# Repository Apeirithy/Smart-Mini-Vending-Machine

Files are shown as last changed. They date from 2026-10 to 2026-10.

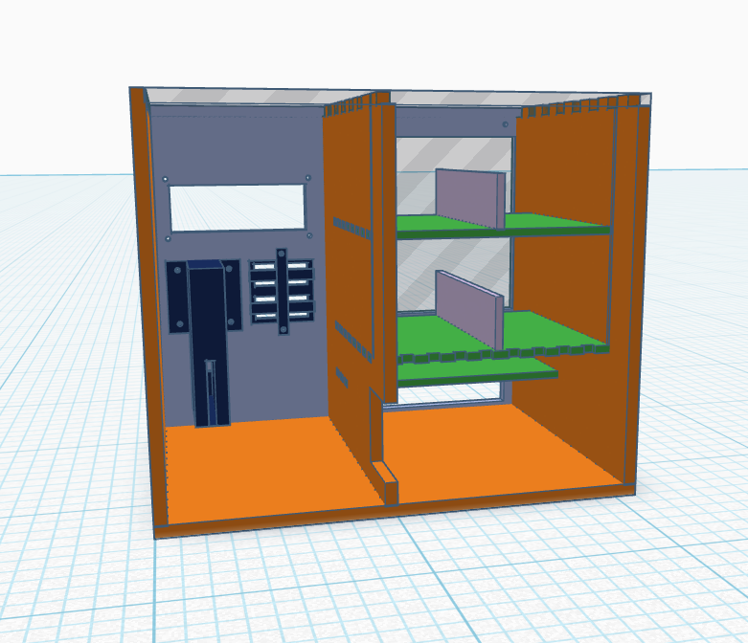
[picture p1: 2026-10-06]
3D_Mechanical_Design/Back View Prototype Design.png

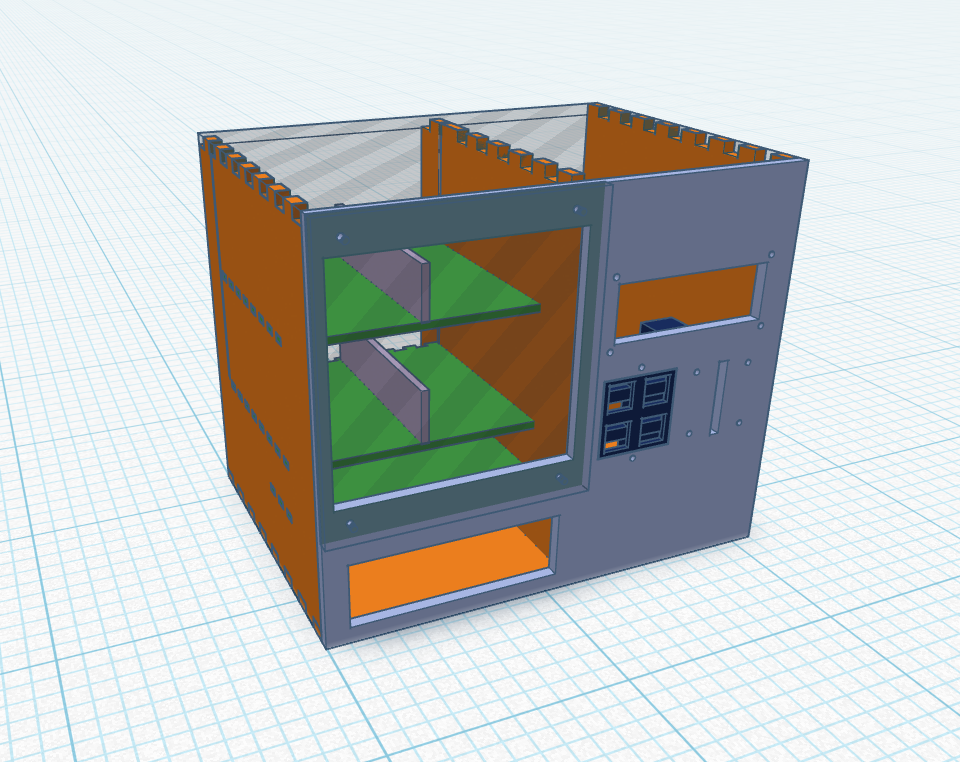
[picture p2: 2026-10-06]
3D_Mechanical_Design/Front View Prototype Design.png

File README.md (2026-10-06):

# Smart Mini Vending Machine for Electrical Components

A microcontroller-based embedded system designed to automatically distribute small electronic components. Built from scratch including custom PCB design, C-based bare-metal firmware (AVR-GCC), and 3D-modeled mechanical enclosures.

## Project Demonstration
* **Live Demo & Explanation:** https://youtu.be/EqsmP9JuczM

## System Architecture & Hardware
The system acts as a fully functional automated dispenser operated by coin insertion.
* **Microcontroller:** Arduino Nano (ATmega328P) acting as the main control unit.
* **Motor Control:** Dual DRV8833 Motor Drivers controlling 4 independent DC motors for product dispensing.
* **Sensors:** 
  * IR Optocoupler (Speed Sensor) for accurate coin insertion detection.
  * IR Obstacle Avoidance Sensors serving as drop detectors to verify successful product dispensation.
* **I/O Management:** Utilized PCF8574 I2C expansion board to manage push-button inputs, saving precious microcontroller pins.
* **Custom PCB:** The entire circuit was routed and engraved on a custom single-layer PCB using EasyEDA, replacing unreliable jumper wires.

> **View Hardware Schematic:** [Click here to view the EasyEDA Schematic](./Hardware_Schematics/Schematic_Vending_Machine.png)

## Mechanical & Enclosure Design
The physical chassis and dispensing mechanism were custom-designed to fit the specific needs of electrical components:
* **Enclosure:** Modeled in Tinkercad and fabricated using 5mm acrylic via laser cutting for a precise and professional finish.
* **Dispensing Mechanism:** Custom 3D-printed spiral pushers (coils) directly coupled to the DC motors.

> **View 3D Layout:** [Click here to view the Tinkercad Layout](./3D_Mechanical_Design/3D_Design_Part.stl)

## Firmware Logic (Finite State Machine)
The firmware is written in pure C (AVR-GCC) and relies on a robust Finite State Machine (FSM) to prevent conflicting operations.
1. **STATE_IDLE:** System awaits a hardware interrupt (PCINT) triggered by the optical coin sensor.
2. **STATE_SELECT:** Activates the I2C button matrix for user selection.
3. **STATE_RUNNING:** Actuates the DRV8833 motor driver until the drop sensor is triggered.
4. **STATE_FINISH:** Halts the motor, displays a "Thank You" message on the I2C 16x2 LCD, and resets the loop.

*A Watchdog Timer (WDT) is implemented to automatically recover the system in case of unexpected execution hangs.*

> **View Logic Flowchart:** [Click here to view the FSM Flowchart](./Firmware_Logic/Flowchart_Vending_Machine.png)

## Academic Report
For full technical specifications, hardware pin-mapping, and testing evaluations, please read the [Full Project Report (PDF)](./Reports/Vending_Machine_Report.pdf).

> **Visual Documentation:** Photos of the final built device, internal wiring, and documentation from the campus exhibition can be found on **pages 25–27** of the report.

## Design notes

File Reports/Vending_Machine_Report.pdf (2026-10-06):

i

## Laporan Tugas Akhir / Final Project

## CPEN6261010 - Microcontroller

## Smart Mini Vending Machine

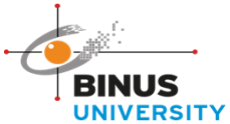
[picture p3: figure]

KELAS – LA40

Dibuat Oleh:

Nicholas Laurensius Halim | 2802428072

Computer Engineering

Faculty of Engineering - Computer Engineering

Binus University

Semester Ganjil 2025/2026

ii

Daftar Isi
Hal
Lembar Sampul
Daftar Isi

i
ii
Bab 1 – PENDAHULUAN | 3
Bab 2 – DESAIN SISTEM DAN METODOLOGI | 6
Bab 3 – IMPLEMENTASI | 12
Bab 4 – HASIL, PEMBAHASAN, KONTRIBUSI | 21
Bab 5 – KESIMPULAN DAN SARAN
Daftar Pustaka
Lampiran-Lampiran
Lampiran 1. Bukti Tambahan project / Link Video Penjelasan Lampiran 2. Datasheet
Lampiran 3. Source Code
Lampiran 4. Video Presentasi

23
24

25
28
29
30

BAB 1. PENDAHULUAN

### 1.1 Latar Belakang

Perkembangan teknologi otomasi dan sistem tertanam (embedded system) telah mendorong penerapan mikrokontroler dalam berbagai bidang, termasuk sistem penjualan otomatis (vending machine). Vending machine konvensional umumnya digunakan untuk menjual makanan atau minuman, namun memiliki keterbatasan dari segi ukuran, biaya, dan fleksibilitas sehingga kurang sesuai untuk kebutuhan penjualan barang berukuran kecil seperti komponen elektronik.

Dalam lingkungan pendidikan, laboratorium, dan pameran teknologi, kebutuhan akan sistem penyediaan komponen elektronik kecil seperti resistor, LED, atau modul sederhana secara cepat dan mandiri semakin meningkat. Sistem manual dinilai kurang efisien karena membutuhkan operator, rawan kesalahan, dan tidak mendukung otomasi. Oleh karena itu, dibutuhkan sebuah sistem vending machine berukuran mini yang sederhana, ekonomis, dan mudah dioperasikan.

Proyek Smart Mini Vending Machine for Electrical Components dirancang
sebagai | solusi | untuk | permasalahan | tersebut | dengan | memanfaatkan
mikrokontroler sebagai pengendali utama, sensor koin sebagai input pembayaran, push button sebagai media pemilihan produk, serta motor DC sebagai aktuator mekanis. Sistem ini menampilkan informasi kepada pengguna melalui LCD berbasis I2C dan bekerja secara otomatis berdasarkan alur logika yang tertanam dalam firmware.

Luaran dari tugas rancang ini berupa sebuah prototipe hardware lengkap dengan firmware yang mampu mendemonstrasikan prinsip kerja vending machine mini secara fungsional, dengan potensi penerapan jangka pendek sebagai media edukasi dan jangka panjang sebagai dasar pengembangan sistem vending machine skala kecil.

### 1.2 Rumusan Masalah

1. Bagaimana merancang sebuah vending machine mini yang mampu mendistribusikan komponen elektronik secara otomatis?
2. Bagaimana | mengimplementasikan | sistem | kontrol | berbasis
mikrokontroler untuk mengelola input koin, pemilihan produk, dan aktuasi motor?

3. Bagaimana merancang sistem yang sederhana, stabil, dan mudah digunakan tanpa menggunakan antarmuka yang kompleks seperti keypad?

### 1.3 Tujuan dan Manfaat

Tujuan dari proyek ini adalah:
1. Merancang dan merealisasikan prototipe vending machine mini berbasis mikrokontroler.
2. Mengimplementasikan sistem kontrol otomatis menggunakan sensor IR, push button, motor DC, dan LCD.
3. Mengembangkan firmware yang stabil dengan mekanisme state machine untuk mengatur alur kerja sistem.
Manfaat dari proyek ini meliputi :
1. Menjadi media pembelajaran praktis dalam memahami sistem embedded dan otomasi.
2. Memberikan solusi sederhana untuk distribusi komponen elektronik kecil secara mandiri.
3. Menjadi dasar pengembangan lebih lanjut menuju sistem vending machine yang lebih kompleks.

### 1.4 Ruang Lingkup

Ruang lingkup perancangan pada proyek ini dibatasi sebagai berikut:
1. Sistem hanya melayani satu transaksi untuk satu kali koin.
2. Pemilihan produk dilakukan menggunakan push button, bukan keypad.
3. Produk yang didistribusikan berupa komponen elektronik kecil.
4. Sistem menggunakan mikrokontroler berbasis Arduino Nano (ATmega328P).

### 5. Perancangan difokuskan pada pembuatan prototipe, bukan produk

komersial.

### 1.1 Tinjauan Pustaka

Vending machine merupakan sistem otomatis yang dirancang untuk mendistribusikan barang kepada pengguna setelah menerima input tertentu, seperti koin atau kartu. Sistem ini umumnya terdiri dari unit input, unit kontrol, dan aktuator mekanis. Pada skala komersial, vending machine memiliki sistem yang kompleks dan berukuran besar sehingga kurang sesuai untuk kebutuhan penjualan barang kecil dalam jumlah terbatas.

Mikrokontroler ATmega328P banyak digunakan dalam sistem embedded karena memiliki konsumsi daya rendah, jumlah pin yang mencukupi, serta dukungan ekosistem pengembangan yang luas. Penelitian dan proyek sebelumnya menunjukkan bahwa mikrokontroler ini efektif digunakan untuk sistem kontrol sederhana hingga menengah, termasuk pengendalian motor DC dan pengolahan input digital.

Sensor koin berbasis pulsa atau logika digital telah banyak diterapkan pada sistem vending machine sederhana. Sensor ini bekerja dengan mendeteksi perubahan logika tegangan saat koin melewati sensor, sehingga dapat digunakan sebagai pemicu transaksi. Selain itu, penggunaan push button sebagai media pemilihan produk dinilai lebih sederhana dan andal dibandingkan keypad, terutama untuk sistem dengan jumlah pilihan terbatas.

Beberapa penelitian dan prototipe vending machine berbasis mikrokontroler telah dikembangkan sebelumnya, namun umumnya ditujukan untuk produk konsumsi dan menggunakan antarmuka yang lebih kompleks. Keunikan dari perancangan ini terletak pada fokus pada distribusi komponen elektronik berukuran kecil, desain sistem yang ringkas, serta penggunaan antarmuka sederhana berbasis tombol yang sesuai untuk lingkungan edukasi dan pameran.

Hasil perancangan yang ditawarkan bersifat konstruktif karena menghasilkan sebuah sistem prototipe vending machine mini yang berfungsi secara nyata, memiliki daya guna sebagai alat pembelajaran, dan dapat dikembangkan lebih lanjut sesuai kebutuhan.

BAB 2. DESAIN SISTEM DAN METODOLOGI

### 2.1 Desain Sistem Secara Umum

Smart Mini Vending Machine for Electrical Components dirancang sebagai sebuah sistem tertanam (embedded system) yang mampu melakukan proses penjualan komponen elektronik secara otomatis. Sistem bekerja dengan mendeteksi koin sebagai input awal, menerima pilihan produk melalui tombol tekan (push button), menggerakkan motor DC untuk mendistribusikan barang, serta menampilkan informasi kepada pengguna melalui LCD berbasis I2C.

Sistem ini dikendalikan oleh sebuah mikrokontroler Arduino Nano yang berfungsi sebagai pusat pengolah data dan pengendali seluruh perangkat input dan output. Seluruh proses dikendalikan menggunakan pendekatan state machine untuk memastikan alur kerja sistem berjalan secara terstruktur dan stabil.

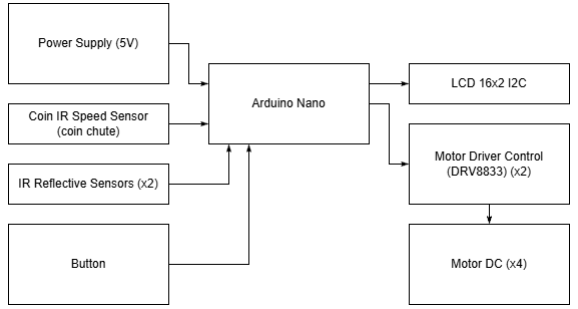
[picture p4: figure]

Blok Diagram Vending Machine

### 2.2 Desain Perangkat Keras

### 2.2.1 Arsitektur Perangkat Keras

Perangkat keras sistem Smart Mini Vending Machine terdiri dari beberapa modul utama, yaitu:

a) Mikrokontroler Arduino Nano digunakan sebagai pusat kendali sistem yang memproses sinyal dari sensor dan tombol, serta mengontrol motor DC dan LCD.

b) Sensor Optocoupler berfungsi untuk mendeteksi masuknya koin sebagai syarat awal untuk mengaktifkan sistem pemilihan produk.
c) Push Button (Melalui PCF8574) digunakan sebagai input pemilihan produk oleh pengguna. Modul PCF8574 digunakan untuk memperluas jumlah input menggunakan komunikasi I2C.
d) Motor DC dan Motor Driver digunakan sebagai aktuator untuk menggerakkan mekanisme pengeluaran produk. Motor driver berfungsi sebagai penguat arus agar motor dapat dikendalikan oleh mikrokontroler.
e) Sensor IR Obstacle Avoidance Module digunakan untuk mendeteksi bahwa produk telah berhasil dikeluarkan dari mesin.
f) LCD I2C digunakan sebagai antarmuka pengguna untuk menampilkan instruksi dan status sistem, seperti “Insert Coin”, “Select Product”, dan “Thank You”.
g) Power Supply, Sistem menggunakan suplai daya yang bersumber dari Adaptor 5V

### 2.2.2 Skema Rangkaian

Skema rangkaian menggambarkan hubungan antar komponen perangkat keras secara detail, termasuk koneksi pin antara Arduino Nano dengan sensor, modul I2C, motor driver, dan motor DC. Skema ini digunakan sebagai acuan dalam proses perakitan sistem dan memastikan seluruh komponen terhubung dengan benar.

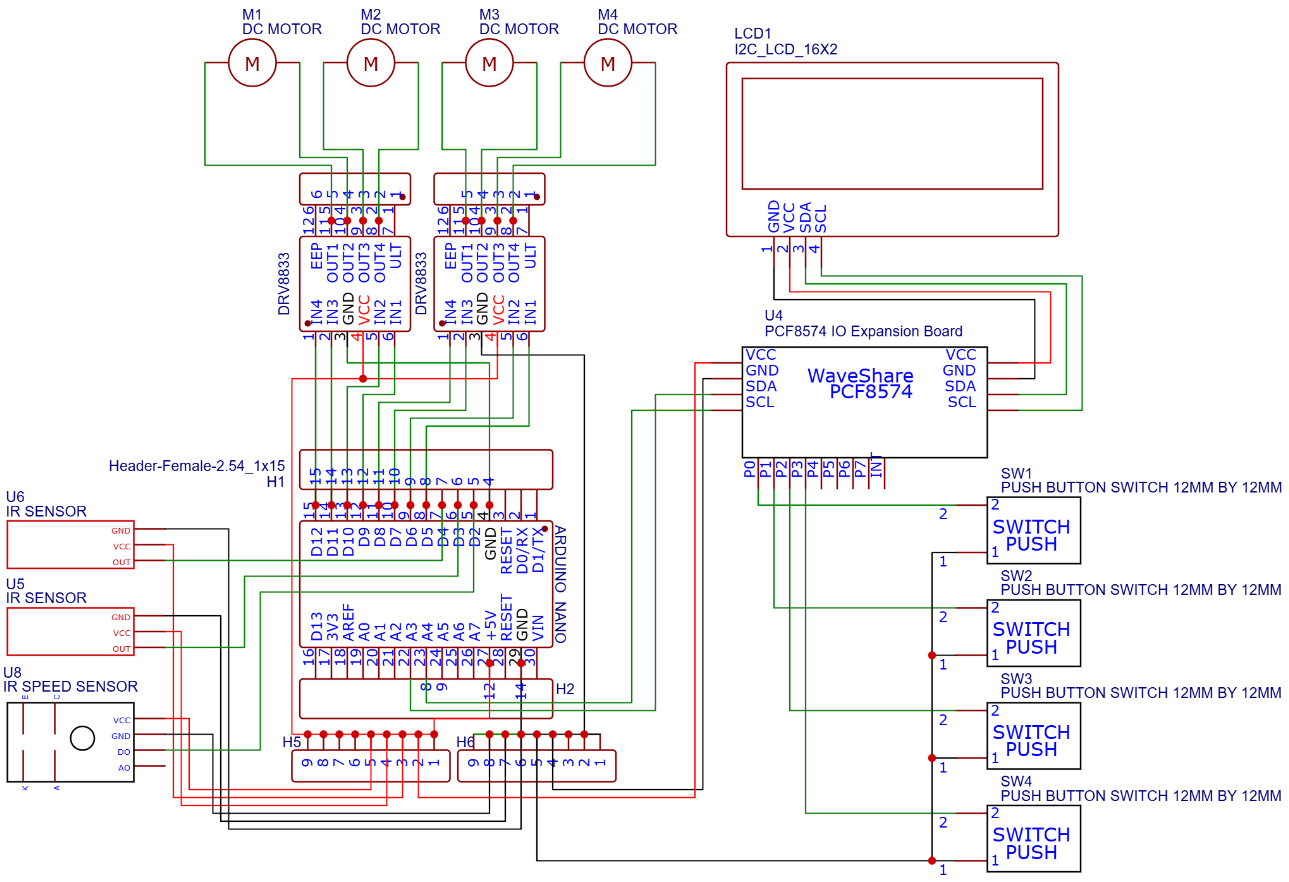
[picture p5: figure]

Skema Rangkaian Vending Machine

### 2.3 Desain Perangkat Lunak

Perangkat lunak pada sistem Smart Mini Vending Machine dikembangkan menggunakan bahasa pemrograman C berbasis AVR. Program dirancang menggunakan pendekatan finite state machine (FSM) untuk memastikan sistem dapat berpindah antar kondisi secara terkontrol dan terhindar dari perilaku tak terduga.

### 2.3.1 Konsep State Machine

Sistem memiliki beberapa kondisi utama, yaitu:

- IDLE: Sistem menunggu koin dimasukkan oleh pengguna dan menampilkan pesan awal.
- SELECT: Sistem menerima input pemilihan produk melalui push button.
- RUNNING: Sistem mengaktifkan motor DC untuk mengeluarkan produk.
- FINISH: Sistem menghentikan motor, menampilkan pesan terima kasih, dan kembali ke kondisi awal.

Pendekatan ini dipilih untuk meningkatkan stabilitas sistem dan memudahkan proses debugging serta pengembangan lanjutan.

### 2.3.2 Flowchart Sistem

Flowchart digunakan untuk menggambarkan alur logika kerja sistem secara visual, mulai dari inisialisasi hingga sistem kembali ke kondisi awal setelah transaksi selesai.

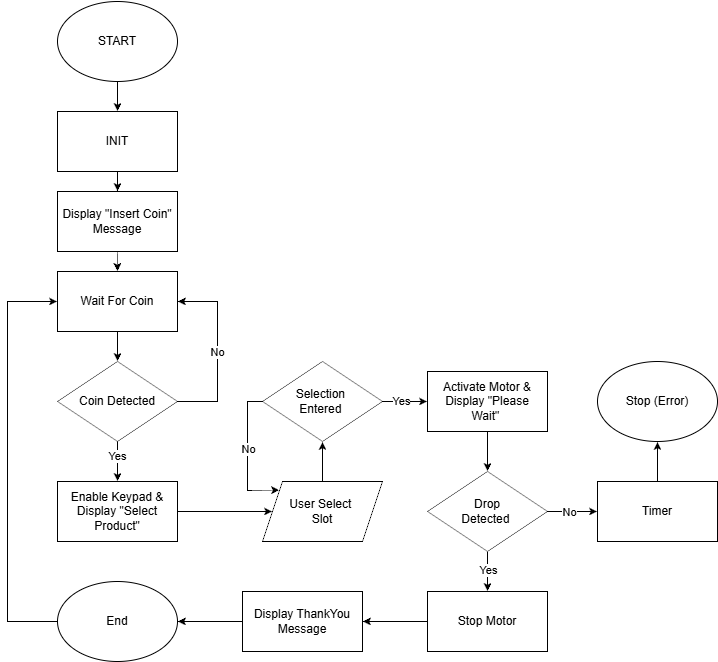
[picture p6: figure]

### 2.3.3 Pseudocode Sistem

Initialize system

Set system state to IDLE

Display "Insert Coin"

Loop forever:

If state is IDLE:

If coin detected:

Change state to SELECT

Display "Select Product"

If state is SELECT:

If button pressed:

Start selected motor

Change state to RUNNING

If timeout occurs:

Return to IDLE

If state is RUNNING:

If drop sensor triggered:

Stop motor

Change state to FINISH

If state is FINISH:

Display "Thank You"

Delay for a short time

Return to IDLE

### 2.4 Metodologi Kerja Sistem

Metodologi kerja sistem dimulai dengan inisialisasi seluruh perangkat keras dan perangkat lunak. Sistem kemudian berada pada kondisi siaga (IDLE) sambil menunggu masukan koin dari pengguna. Setelah koin terdeteksi, sistem berpindah ke mode pemilihan produk.

Pengguna memilih produk menggunakan tombol tekan, yang kemudian diproses oleh mikrokontroler untuk menentukan motor yang akan diaktifkan. Motor DC akan berputar hingga sensor drop mendeteksi bahwa produk telah berhasil dikeluarkan. Setelah proses selesai, sistem menampilkan pesan terima kasih dan kembali ke kondisi awal untuk siap menerima transaksi berikutnya.

### 2.5 Justifikasi Pemilihan Komponen

1. Arduino Nano

Dipilih karena ukurannya yang kecil, jumlah pin yang mencukupi, konsumsi daya rendah, serta kemudahan pemrograman dan debugging.

2. Push Button + PCF8574

Digunakan sebagai alternatif keypad untuk menyederhanakan antarmuka pengguna dan menghemat penggunaan pin mikrokontroler melalui komunikasi I2C.

3. LCD 16x2 I2C

LCD berbasis I2C digunakan sebagai media tampilan informasi kepada pengguna. Penggunaan antarmuka I2C memungkinkan pengurangan jumlah kabel dan pin yang digunakan dibandingkan LCD paralel konvensional. LCD ini dipilih karena memiliki ukuran yang kecil dan harga yang cukup murah.

4. Motor DC RS-310

Motor DC digunakan sebagai aktuator utama untuk menggerakkan mekanisme pengeluaran produk karena bisa bekerja hanya dengan 5V dan memiliki harga yang terjangkau. Motor DC RS-310 juga mampu menghasilkan torsi yang cukup untuk mendorong komponen elektronik berukuran kecil keluar dari mesin.

5. Driver 8833

Motor driver DRV8833 dipilih karena memiliki dua kanal (dual H-bridge) yang mampu mengendalikan dua motor DC secara independen dalam satu modul. Hal ini memungkinkan penghematan ruang dan komponen pada sistem. Selain itu, DRV8833 mampu bekerja pada tegangan rendah dan memiliki kemampuan proteksi arus berlebih (overcurrent protection).

6. IR Obstacle Avoidance Sensor Module

Digunakan untuk memastikan produk benar-benar keluar sebelum sistem menyelesaikan satu siklus transaksi. Dipilih karena harga yang murah dan simpel

7. IR Speed Sensor/ Optocoupler

Sensor koin yang digunakan pada sistem ini berbasis infrared optocoupler (IR speed sensor). Sensor ini dipilih karena memiliki desain berbentuk slot huruf U, yang memudahkan koin untuk melewati jalur sensor tanpa hambatan mekanis yang kompleks.

BAB 3. IMPLEMENTASI

### 3.1 Penjelasan Singkat Sistem yang telah dibuat

Sistem yang telah dibuat merupakan Smart Mini Vending Machine for Electrical Components, yaitu sebuah mesin vending berskala kecil yang dirancang untuk mendistribusikan komponen elektronik secara otomatis. Sistem ini menggunakan koin khusus sebagai metode pembayaran, tombol sebagai media pemilihan produk, serta motor DC sebagai aktuator untuk mengeluarkan barang.

Mikrokontroler Arduino Nano berfungsi sebagai pusat pengendali sistem yang menerima masukan dari sensor koin dan sensor pendeteksi barang, memproses input pengguna, serta mengendalikan motor DC melalui driver motor. Informasi kepada pengguna ditampilkan melalui LCD 16x2 berbasis komunikasi I2C.

### 3.2 Cara Kerja Sistem

Cara kerja sistem Smart Mini Vending Machine diawali dengan kondisi awal sistem dalam keadaan siaga (idle) dan menampilkan pesan “Insert Your Coin” pada LCD. Ketika koin khusus dimasukkan ke dalam slot, sensor IR speed sensor (optocoupler) mendeteksi keberadaan koin dan mengirimkan sinyal ke mikrokontroler.

Setelah koin terdeteksi, sistem berpindah ke mode pemilihan produk. LCD menampilkan pesan “Select Product”, dan pengguna dapat memilih produk menggunakan tombol yang tersedia. Tombol-tombol tersebut terhubung melalui modul I/O expander PCF8574.

Ketika salah satu tombol ditekan, mikrokontroler mengaktifkan motor DC yang sesuai dengan produk yang dipilih. Motor akan berputar untuk mendorong barang keluar dari slot. Sensor IR digunakan untuk mendeteksi jatuhnya barang sebagai indikator bahwa produk telah berhasil dikeluarkan.

Setelah barang terdeteksi, motor akan dihentikan, LCD menampilkan pesan “Thank You”, dan sistem kembali ke kondisi awal untuk melayani pengguna berikutnya.

### 3.3 Perancangan Perangkat Keras (Skematik, Perancangan hardware)

### 3.3.1 Desain Casing

Casing vending machine dirancang menggunakan akrilik dengan ketebalan 5 mm. Pemilihan material akrilik didasarkan pada kemudahan mendesain, biaya yang lebih murah dibanding 3D printing semua bagian, dan tampilan yang rapi dan profesional, serta kemudahan proses manufaktur menggunakan mesin laser cutting.

Desain casing dibuat menggunakan website Tinkercad, kemudian dipotong menggunakan mesin Epilog Laser Cutting untuk memastikan kerapihan hasil akhir.

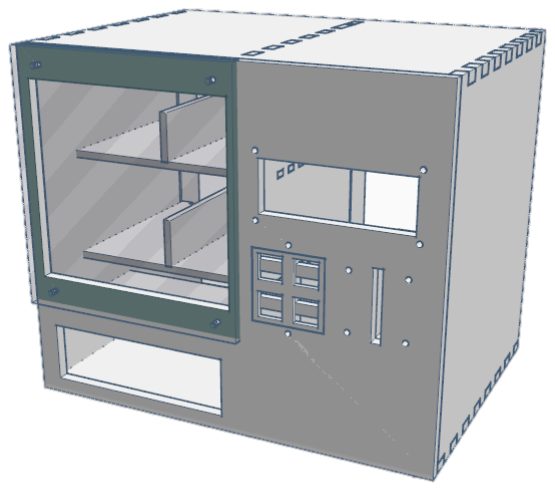
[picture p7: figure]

3D Desain Casing Vending Machine di Tinkercad

### 3.3.2 Mekanisme Mekanik

Beberapa komponen mekanik tambahan digunakan untuk mendukung fungsi sistem, antara lain:

- Slot koin, yang dirancang khusus agar sesuai dengan koin custom.
- Koin custom dengan ketebalan 0,3 mm, yang dirancang agar dapat melewati sensor secara konsisten. Ketebalan ini dipilih karena koin yang terlalu tebal berpotensi tersangkut, sedangkan koin yang terlalu tipis dapat menyebabkan pembacaan sensor tidak stabil.
- Mekanisme | pendorong | barang, | yang | dihubungkan
langsung dengan motor DC untuk mendorong komponen keluar dari slot.
- Casing penahan tombol, agar tombol dapat dipasang dengan rapi dan kokoh pada casing utama.
- Seluruh komponen mekanik tersebut dibuat menggunakan 3D printer, sehingga memungkinkan desain yang presisi dan mudah dimodifikasi.

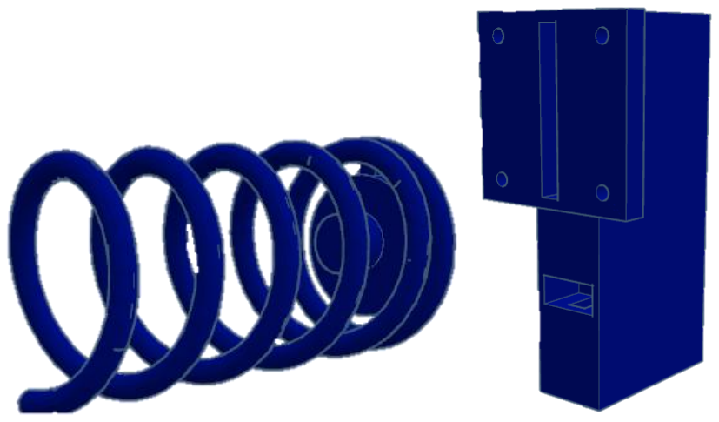
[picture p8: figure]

3D Desain Mekanisme Pendorong & Slot Koin

### 3.3.3 Perancangan PCB dan Rangkaian Elektronik

Rangkaian | elektronik | sistem | dirancang | menggunakan
EasyEDA, yang mencakup mikrokontroler Arduino Nano, driver motor DRV8833, modul I2C LCD, modul PCF8574, sensor IR, dan konektor pendukung lainnya.

PCB dibuat secara mandiri menggunakan metode engraving PCB, sehingga menghasilkan papan rangkaian yang lebih rapi, kuat, dan mengurangi kesalahan koneksi dibandingkan penggunaan kabel jumper.

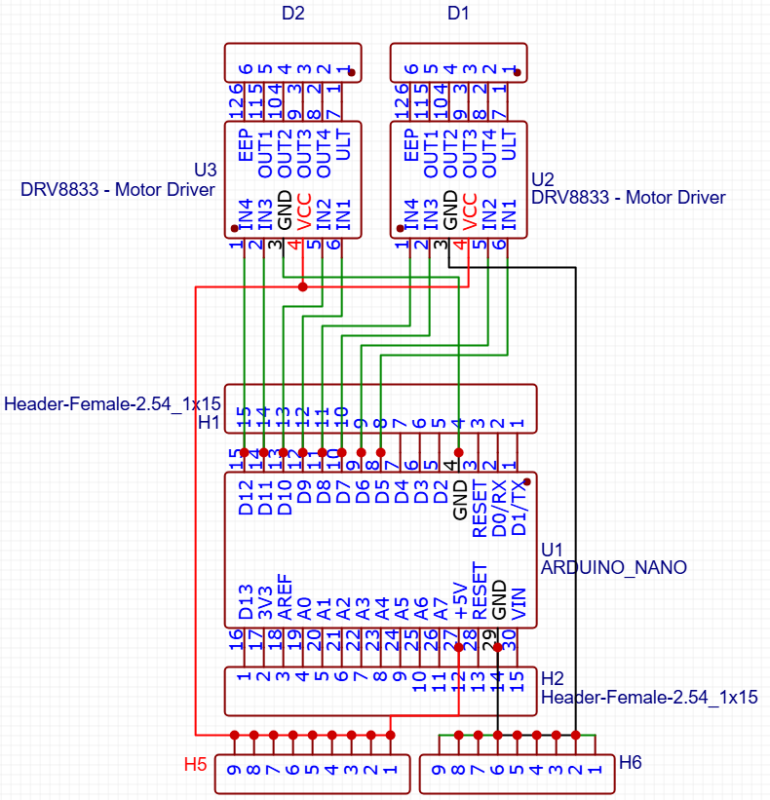
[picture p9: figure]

Skematik Rangkaian PCB di EasyEDA

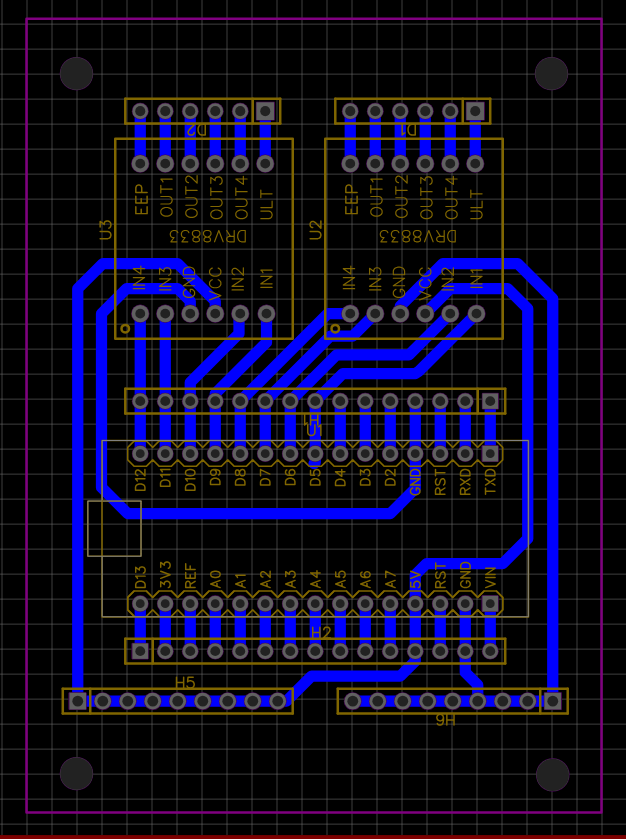
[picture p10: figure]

Layout PCB di EasyEDA

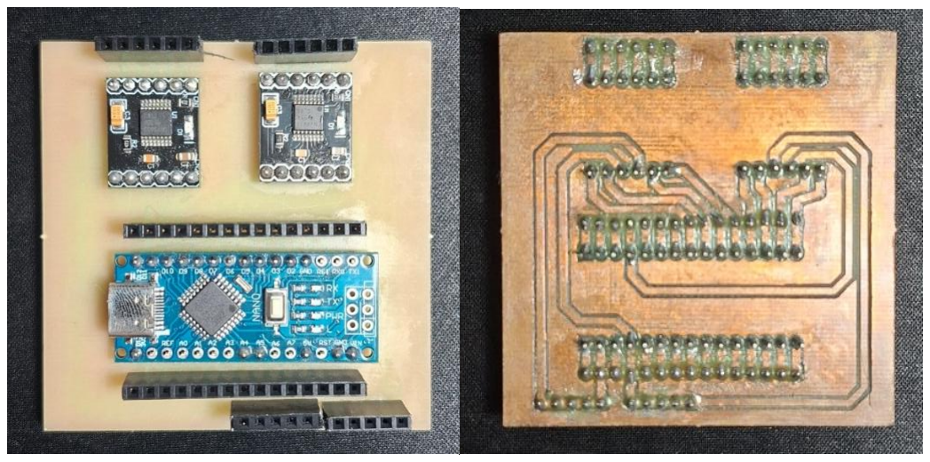
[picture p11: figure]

Hasil Akhir PCB

### 3.4 Perancangan Perangkat Lunak

### 3.4.1 Arsitektur Perangkat Lunak

Perangkat lunak pada Smart Mini Vending Machine for Electrical Components dikembangkan menggunakan bahasa C (AVR-GCC) dan dijalankan pada mikrokontroler ATmega328P.

Sistem menggunakan pendekatan Finite State Machine (FSM) untuk memastikan alur kerja berjalan terstruktur dan stabil. State utama sistem:

- STATE_IDLE – Menunggu koin dimasukkan
- STATE_SELECT – Pengguna memilih produk melalui tombol
- STATE_RUNNING – Motor aktif untuk mengeluarkan produk
- STATE_FINISH – Proses selesai dan sistem kembali ke kondisi awal

### 3.4.2 Library dan Model Perangkat Lunak

Library yang digunakan dalam sistem ini antara lain:

- <avr/io.h> → konfigurasi register I/O
- <avr/interrupt.h> → interrupt sensor koin
- <avr/wdt.h> → watchdog timer
- <util/delay.h> → delay non-blocking sederhana
- i2c.h → komunikasi I2C
- LCD_I2C.h → pengendalian LCD 16x2 berbasis I2C

### 3.4.3 Mekanisme Interrupt Sensor Koin

Sensor koin menggunakan interrupt PCINT agar pendeteksian koin tetap akurat meskipun sistem sedang menjalankan proses lain. Potongan kode utama interrupt sensor koin:

volatile uint8_t coinFlag = 0;

ISR(PCINT2_vect){

if (!(PIND & (1<<PD2))) { // Falling edge sensor koin

coinFlag = 1;

}

}

void setupCoinInterrupt(void){

PCICR |= (1<<PCIE2);

PCMSK2 |= (1<<PCINT18);

sei();

}

Interrupt ini akan mengubah status sistem dari STATE_IDLE ke STATE_SELECT.

### 3.4.4 Logika State Machine Sistem

FSM digunakan untuk mencegah konflik antar proses dan memastikan transisi sistem berjalan aman. Potongan kode utama FSM:

switch(state){

case STATE_IDLE:

if(coinFlag){

coinFlag = 0;

state = STATE_SELECT;

LCD_Clear();

LCD_Print("Select product");

}

break;

case STATE_SELECT:

if(selectedMotor){

state = STATE_RUNNING;

LCD_Clear();

LCD_Print("Please wait :)");

startMotor(selectedMotor);

}

break;

case STATE_RUNNING:

if(productDetected){

state = STATE_FINISH;

}

break;

case STATE_FINISH:

stopAllMotors();

LCD_Clear();

LCD_Print("----Thank You----");

_delay_ms(3000);

state = STATE_IDLE;

break;

}

### 3.4.5 Pengendalian Motor DC

Motor DC dikendalikan menggunakan driver DRV8833 yang memiliki dua channel output sehingga mampu mengontrol dua motor dalam satu IC. Contoh fungsi penggerak motor:

void startMotor(uint8_t motor){

stopAllMotors();

switch(motor){

case 1: PORTD |= (1<<PD5); break;

case 2: PORTD |= (1<<PD7); break;

case 3: PORTB |= (1<<PB1); break;

case 4: PORTB |= (1<<PB3); break;

}

}

### 3.4.6 Watchdog Timer

Watchdog Timer digunakan untuk meningkatkan keandalan sistem dengan mereset mikrokontroler secara otomatis jika terjadi hang atau kesalahan eksekusi.

wdt_enable(WDTO_2S);

while(1){

wdt_reset();

// logika utama sistem

}

### 3.4.7 Output Tampilan LCD

LCD I2C 16x2 digunakan untuk menampilkan status sistem, seperti:

- “Insert your coin”
- “Select product”

- “Please wait” • “Thank You”

BAB 4. HASIL, PEMBAHASAN, KONTRIBUSI

### 4.1 Hasil Pengujian Sistem

Pengujian sistem dilakukan untuk memastikan bahwa Smart Mini Vending Machine for Electrical Components dapat bekerja sesuai dengan tujuan perancangan. Pengujian difokuskan pada fungsi utama sistem, yaitu deteksi koin, pemilihan produk, penggerak motor, serta tampilan informasi pada LCD.

Pengujian dilakukan secara berulang dengan kondisi normal penggunaan pada saat pameran dan pengujian mandiri.
NO | Skenario Pengujian | Kondisi | Hasil Diharapkan | Hasil Pengujian
1 | Deteksi koin | Koin dimasukan ke slot | Sistem mendeteksi koin dan masuk ke menu pemilihan produk | Berhasil
2 Tampilan LCD | awal | Sistem dinyalakan | LCD menampilkan pesan Insert your coin | Berhasil
3 Pemilihan | Produk | Tombol ditekan setelah koin terdeteksi | Sistem memilih produk sesuai tombol | Berhasil
4 Penggerak | motor | Motor dijalankan sesuai pilihan | Motor berputar dan mendorong barang | Berhasil
5 | Sensor drop | Barang jatuh melewati sensor | Motor berhenti dan proses selesai | Berhasil
6 | Tampilan Akhir | Proses Selesai | LCD menampilkan pesan Thank you lalu kembali ke awa | Berhasil
7 Stabilitas | Sistem | Sistem berjalan berulang | Sistem tidak hang / reset tidak terduga | Berhasil

### 4.2 Analisis dan Pembahasan

Hasil pengujian menunjukkan bahwa sistem Smart Mini Vending Machine berhasil mengintegrasikan perangkat keras dan perangkat lunak secara stabil. Sensor koin berbasis infrared optocoupler mampu mendeteksi koin secara konsisten, terutama karena penggunaan koin dengan ketebalan khusus yang telah disesuaikan dengan slot koin. Hal ini meningkatkan keandalan sistem dalam mendeteksi transaksi.
Pemilihan produk menggunakan tombol yang terhubung melalui I²C I/O expander (PCF8574) terbukti efisien karena menghemat pin mikrokontroler dan mempermudah pengembangan sistem. LCD I²C juga mampu menampilkan status sistem dengan jelas kepada pengguna.

Motor DC yang dikendalikan menggunakan driver motor DRV8833 mampu menggerakkan mekanisme pendorong produk secara stabil. Penggunaan driver dua channel memungkinkan pengendalian dua motor secara bersamaan dalam satu modul, sehingga sistem dapat diskalakan untuk beberapa produk.
Secara keseluruhan, sistem telah memenuhi tujuan perancangan sebagai vending machine mini yang fungsional, interaktif, dan mudah digunakan.

### 4.3 Tantangan dan Solusi

Beberapa tantangan yang dihadapi selama perancangan dan implementasi antara lain:
1. Trigger sensor drop terlalu cepat
Solusi: Implementasi deteksi edge dan delay debounce untuk memastikan sinyal valid.
2. Konflik pin dan kesalahan port (PD vs PB)
Solusi: Penyesuaian mapping pin sesuai datasheet ATmega328P.
3. Masalah stabilitas saat motor aktif
Solusi: Penambahan watchdog timer dan manajemen state yang lebih ketat.
4. Kesalahan pembacaan tombol I²C
Solusi: Penyesuaian logika aktif-low pada PCF8574.

### 4.4 Kontribusi Tim

No | Nama/ NIM | Kontribusi
1 | Nicholas Laurensius Halim/ 2802428072 | Perancangan sistem, desain perangkat keras, desain PCB, pemrograman mikrokontroler, integrasi sensor dan motor, desain casing dan mekanik, pengujian dan debugging sistem, pembuatan video progress report, penyusunan seluruh dokumentasi laporan.
2 | Muhammad Ilyas Wijaya/ 2802434705 | Kontribusi pendanaan proyek (50%)

BAB 5. KESIMPULAN DAN SARAN

### 5.1 Kesimpulan

Berdasarkan hasil perancangan, implementasi, dan pengujian yang telah dilakukan pada proyek Smart Mini Vending Machine for Electrical Components, dapat disimpulkan bahwa sistem yang dirancang telah berhasil memenuhi tujuan yang ditetapkan. Sistem mampu mendeteksi koin menggunakan sensor inframerah berbasis optocoupler, memproses input pilihan produk melalui tombol berbasis I2C (PCF8574), serta mengendalikan motor DC menggunakan driver DRV8833 secara andal.
Mikrokontroler Arduino Nano digunakan sebagai pusat kendali sistem dan terbukti mampu mengoordinasikan seluruh proses, mulai dari pendeteksian koin, pemilihan produk, penggerakan motor, hingga tampilan informasi pada LCD I2C. Implementasi state machine pada perangkat lunak berhasil memastikan alur kerja sistem berjalan secara terstruktur dan stabil.
Dengan demikian, proyek ini dapat dikatakan berhasil menghasilkan sebuah prototipe vending machine mini yang fungsional, konstruktif, dan memiliki daya guna yang jelas sebagai media distribusi komponen elektronik skala kecil.

### 5.2 Saran

Meskipun sistem telah berfungsi dengan baik, masih terdapat beberapa keterbatasan yang dapat menjadi peluang pengembangan di masa mendatang. Sistem saat ini hanya mendukung satu koin untuk satu transaksi dan belum mendukung akumulasi multi-koin atau pengaturan harga yang bervariasi untuk setiap produk.
Selain itu, sistem belum dilengkapi dengan fitur pemantauan daya atau proteksi lanjutan terhadap kondisi motor seperti overcurrent atau stall detection. Tampilan antarmuka pengguna juga masih bersifat sederhana dan dapat ditingkatkan dengan menu yang lebih interaktif atau indikator status tambahan. Untuk pengembangan selanjutnya, disarankan agar sistem dilengkapi dengan:
- Fitur multi-koin dan pengaturan harga produk.
- Sistem monitoring arus dan tegangan motor untuk meningkatkan keandalan.
- Penyimpanan data transaksi menggunakan EEPROM atau media penyimpanan eksternal.
- Pengembangan desain mekanik agar lebih modular dan mudah dirawat.
- Integrasi metode pembayaran non-tunai sebagai inovasi lanjutan.

DAFTAR PUSTAKA

Atmel Corporation. (2016). ATmega328P 8-bit AVR Microcontroller Datasheet. Microchip Technology Inc., San Jose.

Banzi, M., & Shiloh, M. (2014). Getting Started with Arduino. 3rd Edition. Maker Media, Sebastopol.

Heryanto, M. A., & Adi, W. (2008). Pemrograman Mikrokontroler AVR ATmega8535. Informatika, Bandung.

Rashid, M. H. (2014). Power Electronics: Circuits, Devices, and Applications. 4th Edition. Pearson Education, New Jersey.

Suyanto. (2018). Sistem Tertanam (Embedded System). Andi Offset, Yogyakarta.

Lampiran 1. Bukti Tambahan project / Link Video Penjelasan
- Dokumentasi Alat

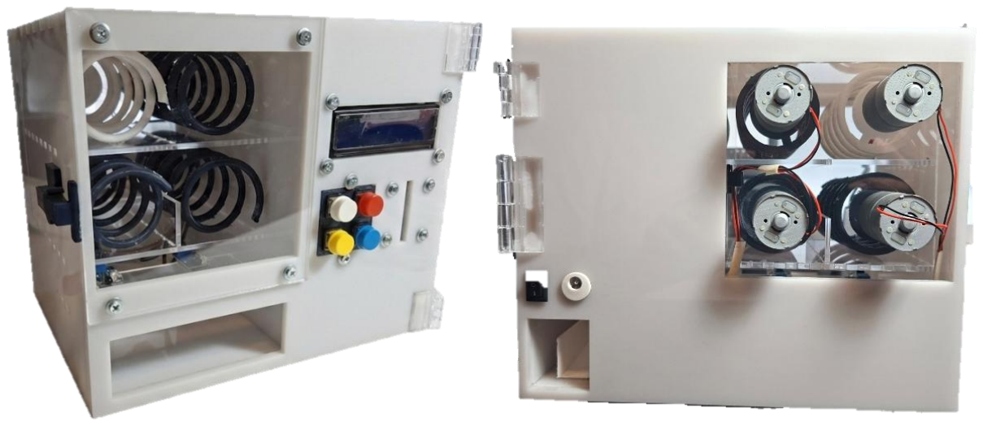
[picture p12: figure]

- Desain 3D

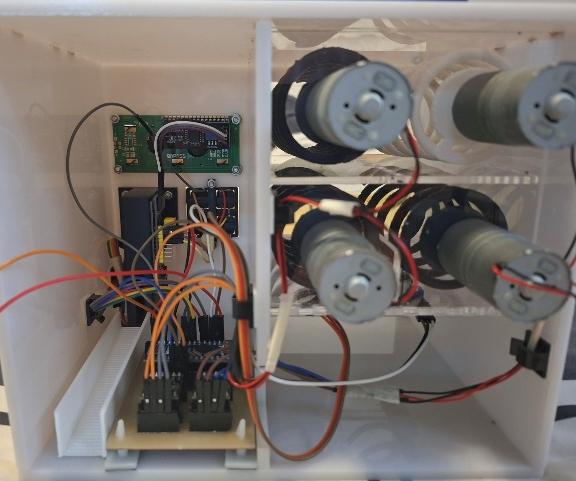
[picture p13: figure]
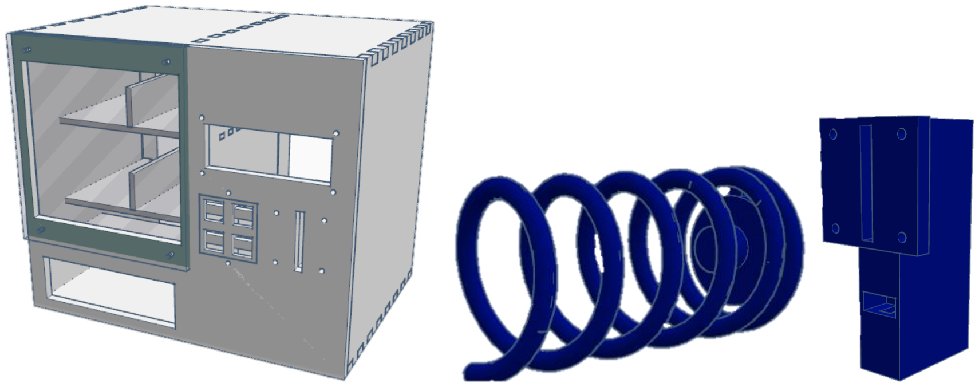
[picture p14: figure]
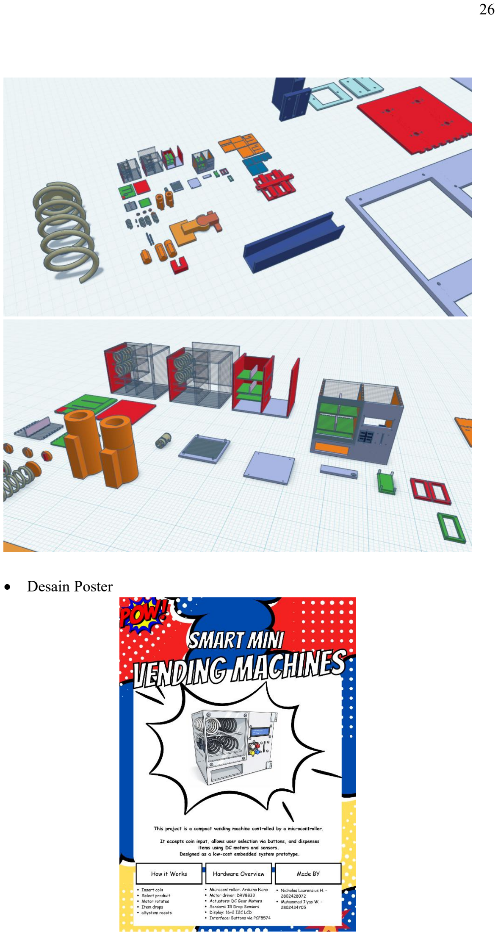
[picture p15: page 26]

- Desain Poster

- Dokumentasi Pameran

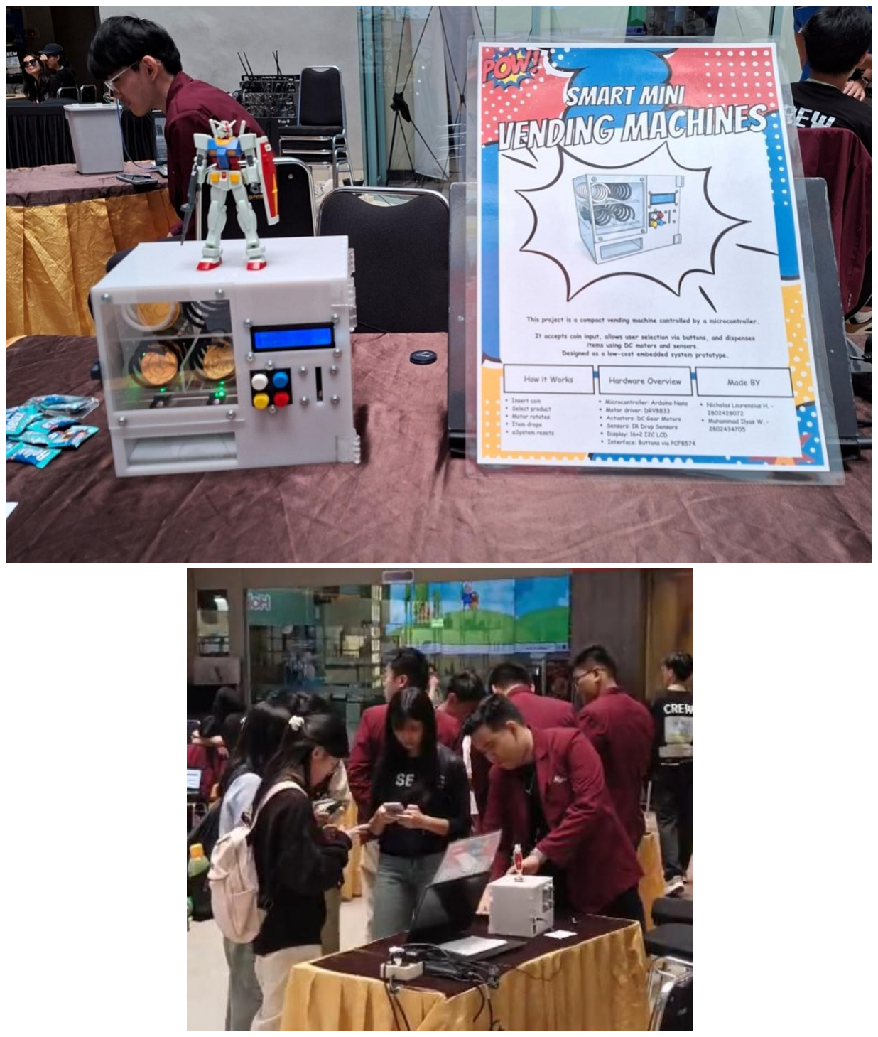
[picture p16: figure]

Lampiran 2. Datasheet
1. Arduino Nano (ATmega328P)
Pabrikan: Microchip
Fungsi: Mikrokontroler utama sistem.
Spesifikasi penting: 5V, 16 MHz, 32 KB Flash, I²C, SPI, UART. Datasheet:
https://docs.arduino.cc/resources/datasheets/ATmega328P-datasheet.pdf
2. Driver Motor DRV8833 H-Bridge
Pabrikan: Texas Instruments
Fungsi: Mengendalikan dua motor DC (dual H-bridge). Alasan: 2 channel dalam satu IC, efisien, cocok untuk 5V. Datasheet:
https://www.ti.com/lit/ds/symlink/drv8833.pdf
3. Sensor Drop – Infrared Obstacle Avoidance Sensor Module Fungsi: Mendeteksi barang sudah jatuh.
Alasan: Murah, jarak sensor pendek sehingga cocok.
Datasheet:
https://studylib.net/doc/25541782/arduino-ir-infrared-obstacle-avoidance-sensor-module
4. LCD 16×2 + I2C Backpack (PCF8574)
Pabrikan IC: NXP
Fungsi: Menampilkan status sistem.
Spesifikasi: 16×2, 5V, I²C (alamat 0x27 / 0x20).
Datasheet:
https://www.nxp.com/docs/en/data-sheet/PCF8574_PCF8574A.pdf
5. I/O Expander PCF8574 (Button Input)
Pabrikan: NXP
Fungsi: Membaca tombol via I²C.
Spesifikasi: 8-bit I/O, 5V.
Datasheet:
https://www.nxp.com/docs/en/data-sheet/PCF8574_PCF8574A.pdf
6. Push Button
Fungsi: Input pilihan produk.
Tipe: Momentary, Normally Open (NO). Referensi:
https://components101.com/switches/push-button

Lampiran 3. Source Code
Source code lengkap dari sistem Smart Mini Vending Machine for Electrical Components tidak dicantumkan secara penuh dalam laporan ini karena keterbatasan ruang. Seluruh kode program, termasuk file utama (main.c) dan library pendukung (I2C dan LCD), dapat diakses melalui repositori GitHub berikut:

Link GitHub:
https://github.com/Apeirithy/smart-mini-vending-machine

Lampiran 4. Video Presentasi

Link Google Drive
https://drive.google.com/file/d/1XK9UZl6ltvrmiSce3q-cIV0SQFHHOPXH/view?usp=sharing

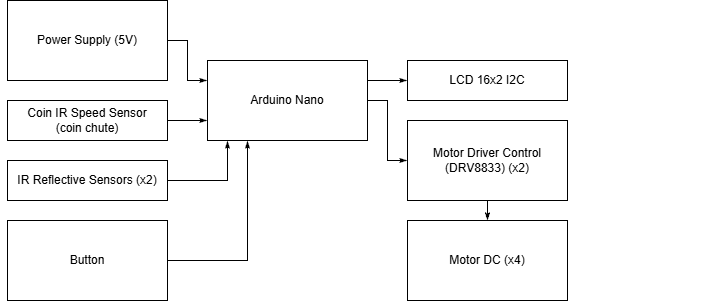
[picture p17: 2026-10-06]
Hardware_Schematics/Block Diagram Vending Machine.png

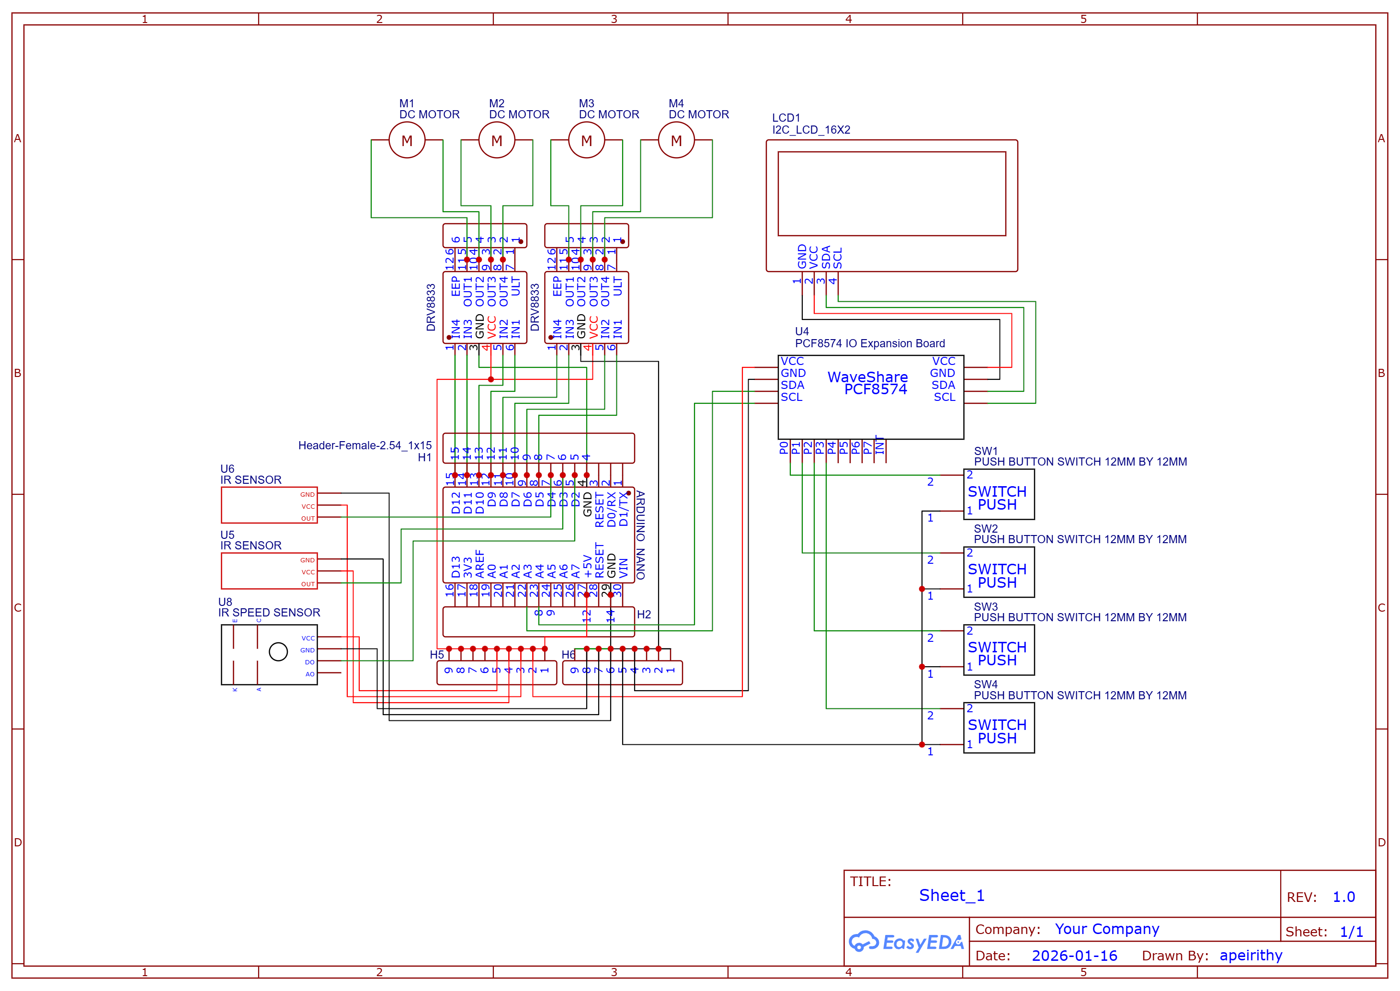
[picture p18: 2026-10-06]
Hardware_Schematics/Schematic_Vending_Machine.png

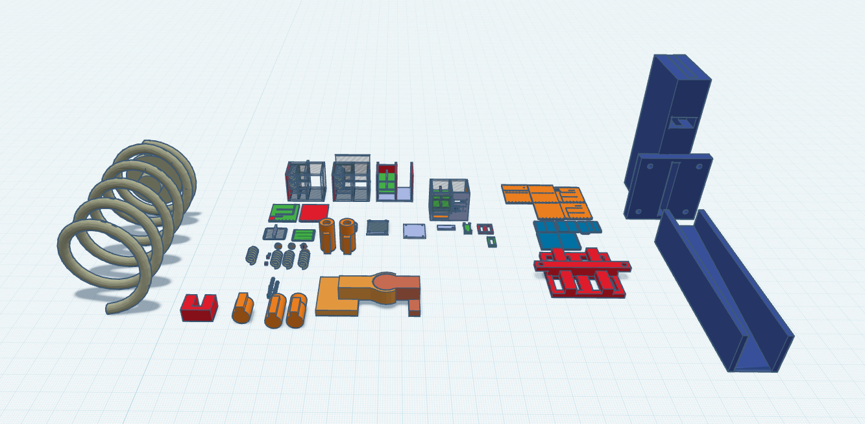
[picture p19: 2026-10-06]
3D_Mechanical_Design/Tinkercade Screenshot.png

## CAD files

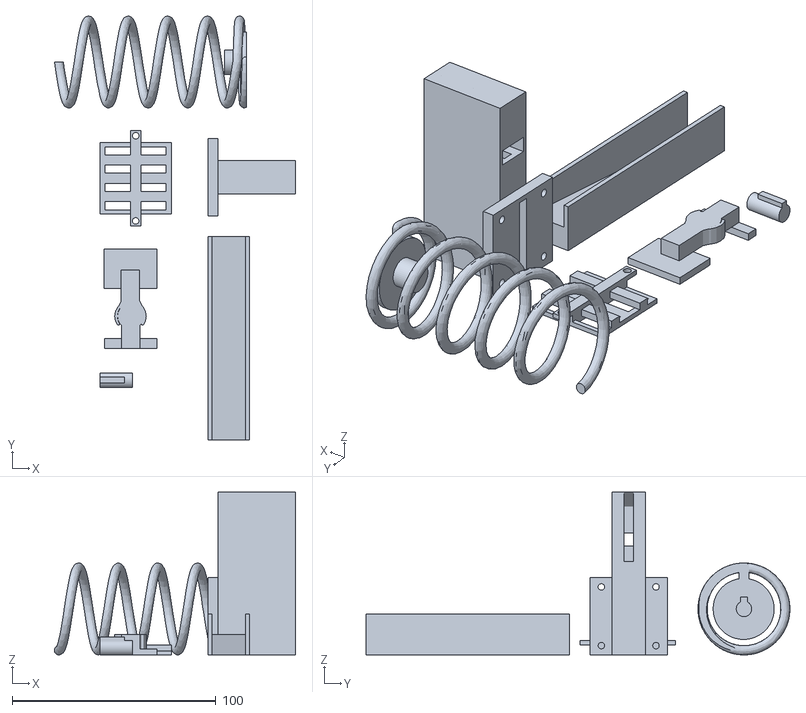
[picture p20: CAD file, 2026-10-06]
3D_Mechanical_Design/3D_Design_Part.stl
118.4 x 208.2 x 80.0
